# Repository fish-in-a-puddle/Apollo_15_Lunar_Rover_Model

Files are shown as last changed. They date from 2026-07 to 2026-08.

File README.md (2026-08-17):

# Apollo 15 Lunar Rover Model v0
A Bluetooth-controlled model of the Apollo 15 lunar rover using an Arduino Nano and an HC-05 Bluetooth module.

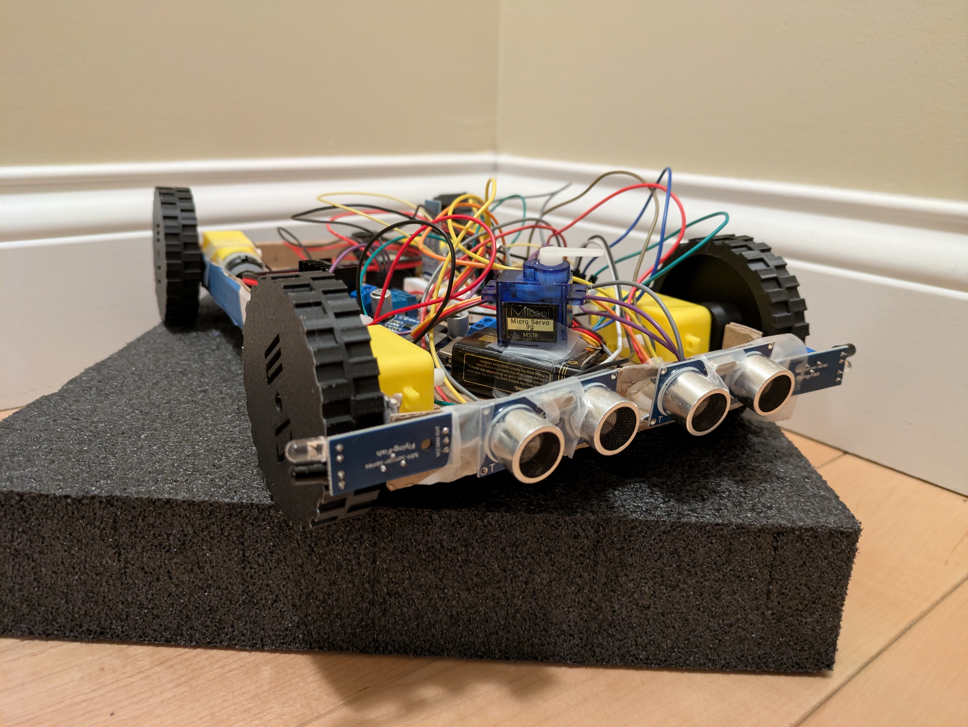
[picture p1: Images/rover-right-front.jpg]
Watch the demo! (https://youtu.be/fayXKmGm4Ek?si=QLX--hcnvoJ-vxXC)


Watch the demo on YouTube [here](https://youtu.be/fayXKmGm4Ek?si=QLX--hcnvoJ-vxXC).

#### Check out the project on Stardance! https://stardance.hackclub.com/projects/1942

## Description
The Apollo 15 Lunar Rover Model is a robot controlled by Bluetooth designed to look as similar as possible to the actual lunar roving vehicle used by Commander David Scott and Lunar Module Pilot James Irwin during the Apollo 15 mission. It can be driven using Bluetooth or set to navigate on its own using two ultrasonic sensors and two IR sensors. The ultrasonic sensors detect obstacles in the path of the rover as it moves forward and the IR sensors are used to check which direction is clear to turn backwards when the rover encounters an obstacle. It also has two LED headlights which can be turned on and off using bluetooth or set to turn themselves on and off depending on the light level detected by a photoresistor. The rover is powered by two 9v batteries: one to power the Arduino, HC-05 module and other components through a 9v-5v buck converter and one to provide power to the motors.

At the moment, the model doesn't look very similar to the actual roving vehicle. This is because the current version of the robot is a prototype built with cardboard to test the code and capabilities of the sensors. Version 0 is being shipped simply to show the process of creating the eventual version 1, which will feature a 3D printed chassis, an improved control app, and will resemble the actual rover much more. The rover is not very sturdy and is intended to be used as an educational tool or to be driven inside.

## Inspiration 
After watching NASA's contract award livestream and seeing some cool designs for future lunar rovers, I was inspired to make a robot modeled after the Apollo 15 Lunar Roving Vehicle. While the current version admittedly looks nothing like the actual rover, I am working on designing a 3d-printable chassis and accessories to pay tribute to the only lunar rover used during the Apollo missions.

The actual lunar roving vehicle

## Getting started
To get started with the current version of the Lunar Rover Model, you will first need to build the cardboard chassis. For instructions on building and wiring the rover, check out [this guide](Construction/building_the_chassis.md).

Once the chassis is built and the components are wired, it is time to flash the firmware to the Arduino. If you want your rover to simply drive itself around with no help from a driver, copy the code from lunar-rover-obstacle-detectv0.4.ino and paste it in the Arduino IDE. You can also download the file, place it in a folder named [lunar-rover-obstacle-detectv0.4](Firmware/lunar-rover-obstacle-detectv0.4.ino) and open it in the IDE. If you want the rover to be able to be driven or to be set to self-navigation, copy the code from [lunar-rover-completev0.2.ino](Firmware/lunar-rover-completev0.2.ino) and paste it in the Arduino IDE. Before flashing the code to the Arduino, you MUST disconnect the Bluetooth module from the Arduino. This is because if you don't, the Arduino will prioritize its serial communication with the Bluetooth module over the USB connection and you will get an error message.

To control the rover with Bluetooth, you will have to install a controller app on your device. I have used this one with great results: https://play.google.com/store/apps/details?id=com.tools.ArduinoBluetooth on Android. You will also need to make the buttons in the app send the correct code to the Arduino. The serial codes are as follows:

Forward = w

Backwards = s

Left = a

Right = d

Left backwards = z

Right backwards = c

Stop = x

Auto drive on = r

Auto drive off = e

Lights on = f

Lights off = g

Lights auto = h

Your configuration will probably look something like this:

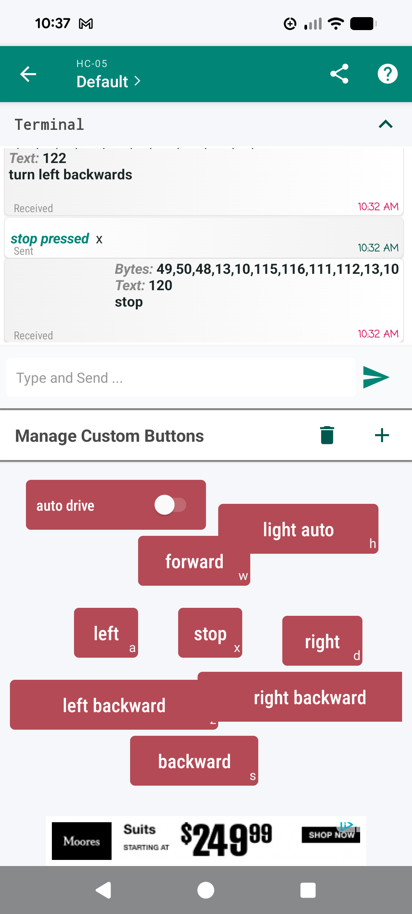
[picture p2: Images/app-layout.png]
Screenshot of app layout


After configuring the buttons in the app, you will be able to control the rover with your mobile device. If you use an iOs device, you may have to do some troubleshooting to find an app that works well. I was planning to make a custom app for the rover, but I don't know much about it and I wanted to focus on the rover itself. If anyone would like to make an app for this project, they are welcome to and I would appreciate if they let me know.

## Troubleshooting

If you are having issues with the motors, check that you have connected GND on the motor driver board to the ground rail on the breadboard as well as the ground of the battery.

If the rover is moving backwards randomly when when self-navigation is enabled, adjust the angle of the ultrasonic sensors. If they are tilted down they will pick up the floor as an obstacle.

If you are having trouble reconnecting the HC-05 to your phone, try making your phone "forget" the device and pair it again. You may be asked to enter a PIN to connect to the module. The code is usually 1234 or 0000.

If you encounter other problems, feel free to send a question to fish.in.a.puddle42@gmail.com. I'll see if I can help.

## Bill of Materials
|ITEM NAME |QTY |PRICE (CAD) |PRICE (USD) |LINK |NOTES |
|---|----|---|---|---|---|
|ELEGOO Arduino Nano | x1 | $33 | $23.68 | https://www.amazon.ca/ELEGOO-Pre-soldered-ATmega-Compatible-Arduino/dp/B0D5LYFRQP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 | The Arduino board used for the rover (Comes in a pack of three)|
|DC Hobby Motors | x4 | $6.59 | $4.70 | https://www.aliexpress.com/item/1005007259961932.html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| |
|L298N Motor Driver | x1 | $2.15 | $1.15 | https://www.aliexpress.com/item/1005012608321443.html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 | |
|HC-05 Bluetooth module | x1 | $6.90 | $5 | https://www.universal-solder.ca/product/hc-05-bluetooth-module-master-slave/?wmc-currency=CAD | The bluetooth module used for the rover |
|9v to 5v buck converter  | x1 | $4.84 | $3.49 | https://www.aliexpress.com/item/1005010708910916.html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 | |
|Ultrasonic sensor | x2 | $4 | $2.88 | https://www.universal-solder.ca/product/hc-sr04-ultrasonic-distance-sensor-module-2cm-400cm-range/ | Buy two |
|IR sensor | x2 | $1.12 | $0.81 | https://www.aliexpress.com/item/1005009143740555.html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 | Buy two |
|220 Ω resistor | x1 | $4.27 | $3.08 | https://www.aliexpress.com/item/1005011767578775.html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 | Pack of 20 |
|Photoresistor | x1 | $1.61 | $1.16 | https://www.amazon.ca/dp/B09ZTQL935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 | Pack of 20 |
|Yellow LED | x2 | $4 | $2.88 | https://www.universal-solder.ca/product/100-x-led-yellow-3mm-round-tinted-clear-standard-package-t-1/ | Pack of 100 |
|Micro Servo Motor | x1 | $8.49 | $6.12 | https://www.aliexpress.com/item/1005010200002677.html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 | |
|Rechargeable 9v batteries| x2 | $3.48 | $2.51 | https://www.aliexpress.com/item/1005007104927891.html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 | Pack of 10 |
|9v battery connectors | x2 | $3 | $2.16 | https://www.amazon.ca/Battery-Connector-Leather-Housing-Connection/dp/B0DHY6VX3L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 | Pack of 10 |
|On/Off rocker switch | x2 | $2 | $1.45 | https://www.amazon.ca/Boat-Rocker-Switch-5Pcs-Position/dp/B0DCNQHKDB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 | Pack of 5 |

## Credits

Original wheel models: https://www.thingiverse.com/thing:5636299

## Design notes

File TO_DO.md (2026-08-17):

# Hardware:
- [x] Put together cardboard frame
- [x] Run test sketch
- [x] Test 5v converter
- [x] Add servo, photoresistor and LEDs
- [ ] Model frame
- [x] Find better wheels

# Software:
- [x] Write test sketch
- [x] Write sketch for bluetooth 
- [x] Make initial app
- [x] Make first draft of final sketch integrating bluetooth and obstacle detection
- [x] Define the rest of the bluetooth recv valuesl

# Shipping prep:
- [x] Update README with instructions for building frame, wiring, flashing code
- [x] Make wiring simulation
- [x] Sort files into folders
- [x] Include instructions for app

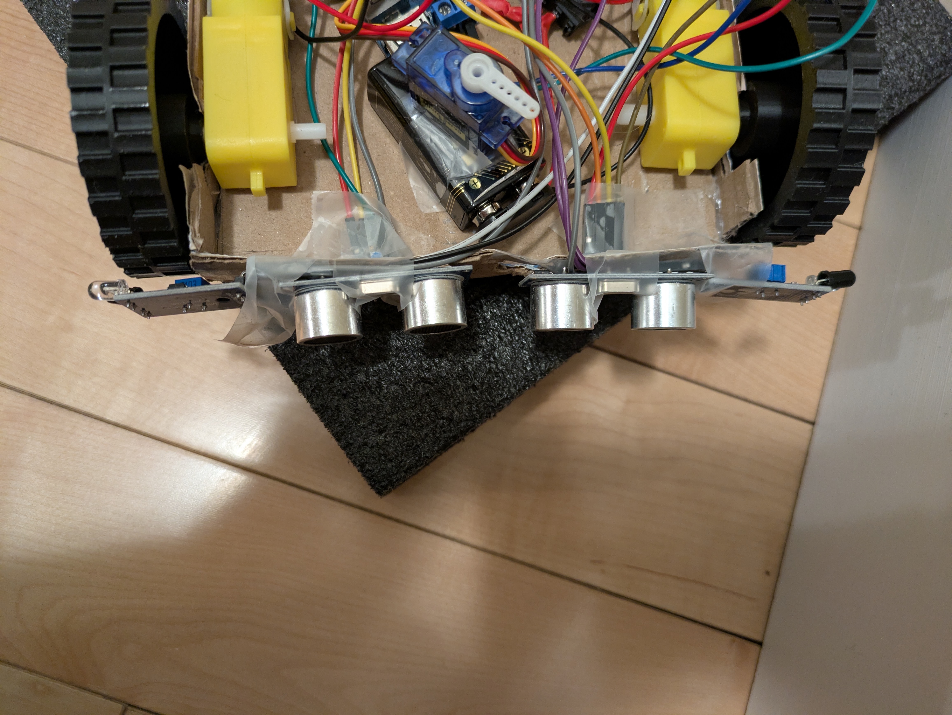
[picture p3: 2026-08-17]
Images/rover-front-top.jpg

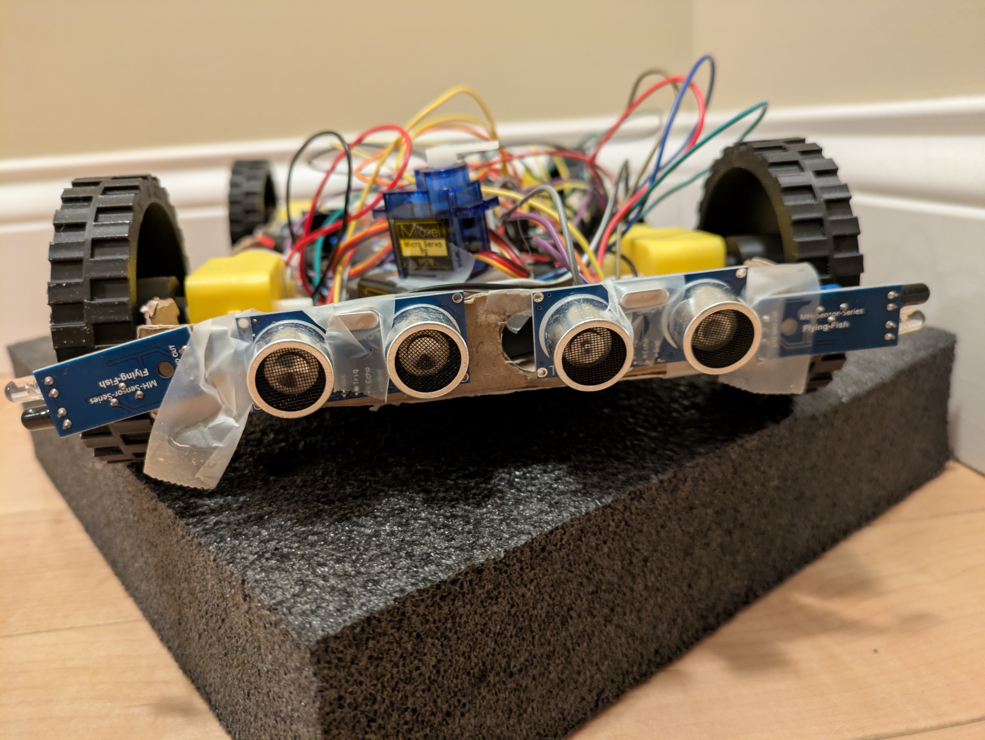
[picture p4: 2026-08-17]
Images/rover-front-closeup.jpg

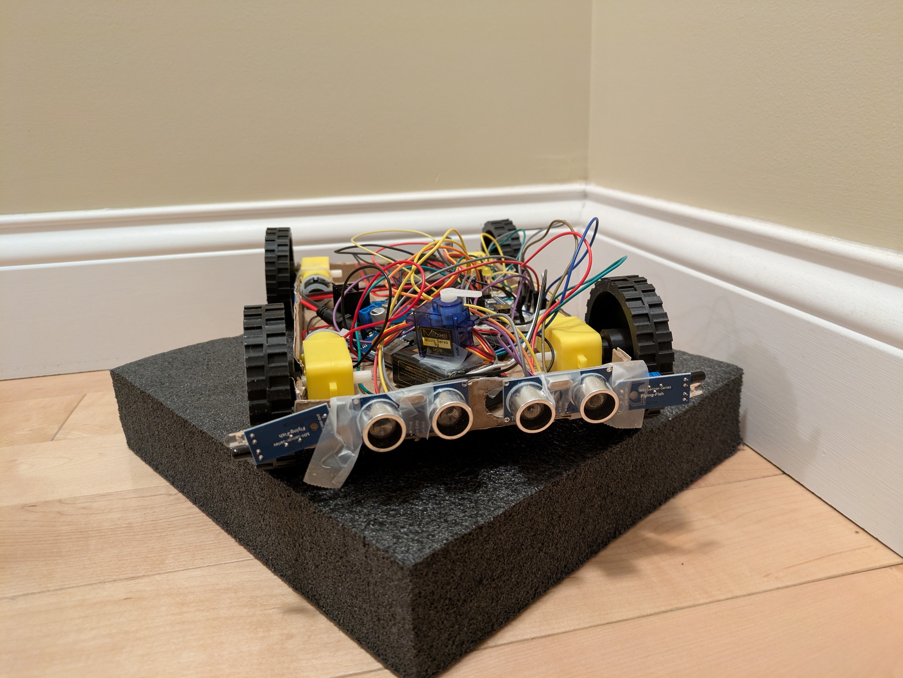
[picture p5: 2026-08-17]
Images/rover-front.jpg

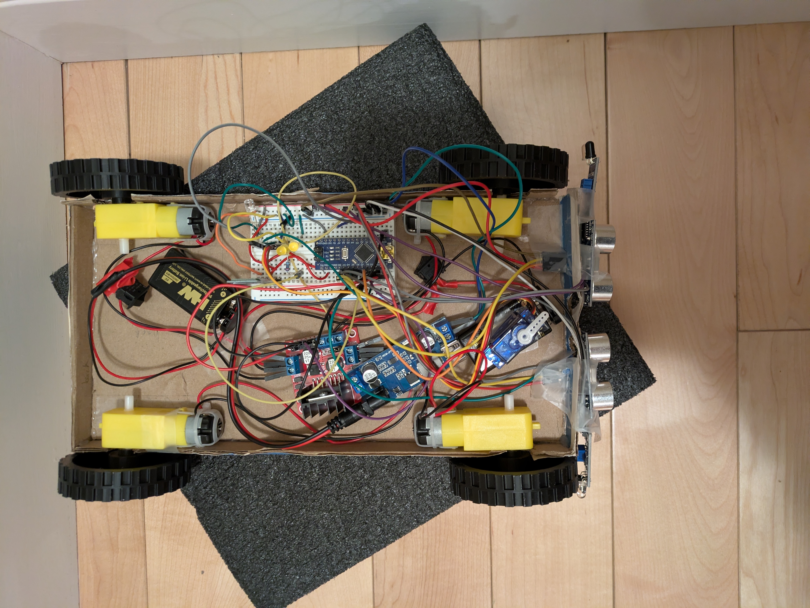
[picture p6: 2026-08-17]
Images/rover-top.jpg

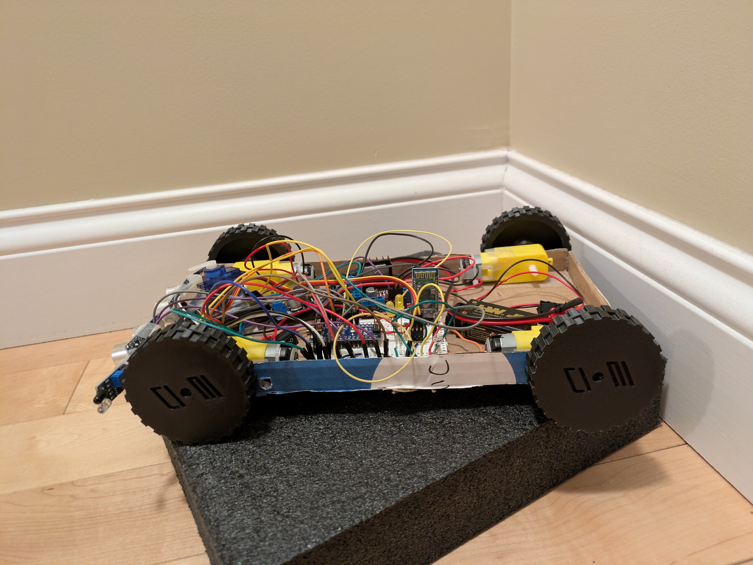
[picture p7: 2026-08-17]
Images/rover-left-side.jpg

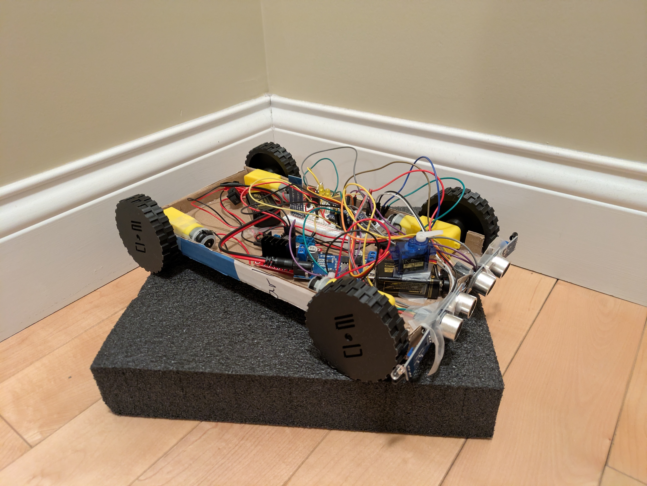
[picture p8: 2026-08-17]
Images/rover-right-side.jpg

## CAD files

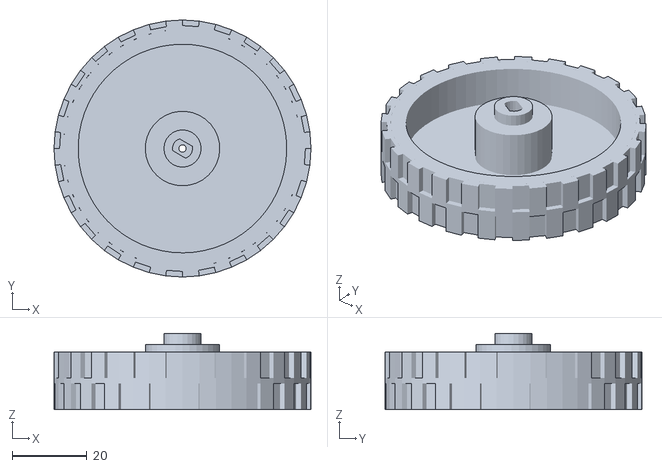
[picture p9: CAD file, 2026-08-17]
Construction/lunar-rover-wheels.stl
69.0 x 69.0 x 20.5

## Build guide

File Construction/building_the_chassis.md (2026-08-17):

# Building the chassis

To get started with the current version of the Lunar Rover Model, you will first need to build the cardboard chassis. The dimensions are as follows:
- Bottom plate: 140x280mm
- Side plates: 280x20mm
- Front & back plates: 140x20mm

Cut out one piece of cardboard for the bottom plate, two for the side plates and two for the top plate. Use a hot glue gun to glue the pieces together in a box shape. Arrange the yellow motors in the box and mark where the shaft should poke out. Use a pencil or hobby knife to create a generous hole to allow the shaft to turn freely. 

You will also need to 3D print four copies of the wheel provided in the "Construction" folder. When they are ready, you will have to line up the shaft of the motor to fit into the slot in the wheel. (You may have to sand the inside of the slot a bit if it's too tight.)

Position one IR sensor on each side of the front plate, making sure that the wheels don't block their range. Use a piece of masking tape or electrical tape to secure each one in place. Position the two ultrasonic sensors in between the IR sensors, with one or two centimeters in between them (it's okay if they overlap with the IR sensors) and push the four-pin headers through the cardboard. Use a small piece of tape to secure the top so they face forward.

rover-front-closeup

Place the Arduino Nano on a half-size breadboard and stick the breadboard in the box. Wire the Arduino, sensors, LEDs, photoresistor, servo motor and HC-05 Bluetooth module as shown in the diagram. Secure the motor driver board in the box as well and wire the motors. Be sure to connect a common ground between the Arduino and the motor driver board.

circuit diagram

Before adding either of the batteries, you will have to cut the red wire of both 9v battery connectors and solder an on/off switch to each one. This will make it so you don't have to pull apart your wiring to turn off the rover. When the switches are soldered and the connections wrapped in electrical tape to prevent short-circuits, connect one of the batteries to the motor driver board and the other to a 9v-5v buck converter. Connect the other side of the converter to the power and ground rails of the breadboard; and connect the 5v and GND pins of the Arduino to their respective rails.

If you are having trouble figuring out where the parts are supposed to go, check the photo gallery to see images of my configuration. It is very messy because this is a prototype so they may or may not be helpful to you. You may have to be creative in your configuration of the chassis, but as long as the wiring matches the diagram, the code will work.

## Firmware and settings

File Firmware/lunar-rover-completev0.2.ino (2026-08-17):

// The current Servo library is required for this program
#include <Servo.h>

// Establish pins and variables
const int motorrp = 11;
const int motorrn = 10;
const int motorlp = 13;
const int motorln = 12;
const int led = 7;
const int trigPin2 = 8;
const int echoPin2 = 3;
const int trigPin = 5;
const int echoPin = 6;
const int irr = 2;
const int irl = 4;
const int lightDetect = A0;
int lightLevel;
long duration;
int distance;
int distance2;
int obstacleRight;
int obstacleLeft;
int autoDrive = 0; 
int autoLights;
int btIn;
int ran;

Servo sweepServo;

void setup() {
    // Begin serial communication with the bluetooth module
    Serial.begin(9600);
    // Set pin modes and attach servo
    pinMode(motorrp, OUTPUT);
    pinMode(motorrn, OUTPUT);
    pinMode(motorlp, OUTPUT);
    pinMode(motorln, OUTPUT);
    pinMode(led, OUTPUT);
    pinMode(trigPin2, OUTPUT);
    pinMode(echoPin2, INPUT);
    pinMode(irr, INPUT);
    pinMode(irl, INPUT);
    pinMode(trigPin, OUTPUT);
    pinMode(echoPin, INPUT);
    sweepServo.attach(9);
    sweepServo.write(90);
}

// Establish functions for the rover's movement
void goForward() {
    digitalWrite(motorrp, HIGH);
    digitalWrite(motorrn, LOW);
    digitalWrite(motorlp, HIGH);
    digitalWrite(motorln, LOW);
}

void goBackward() {
    digitalWrite(motorrp, LOW);
    digitalWrite(motorrn, HIGH);
    digitalWrite(motorlp, LOW);
    digitalWrite(motorln, HIGH);
}

void turnRight() {
    digitalWrite(motorrp, LOW);
    digitalWrite(motorrn, LOW);
    digitalWrite(motorlp, HIGH);
    digitalWrite(motorln, LOW);
}

void turnRightBackwards() {
    digitalWrite(motorrp, LOW);
    digitalWrite(motorrn, LOW);
    digitalWrite(motorlp, LOW);
    digitalWrite(motorln, HIGH);
}

void turnLeft() {
    digitalWrite(motorrp, HIGH);
    digitalWrite(motorrn, LOW);
    digitalWrite(motorlp, LOW);
    digitalWrite(motorln, LOW);
}

void turnLeftBackwards() {
    digitalWrite(motorrp, LOW);
    digitalWrite(motorrn, HIGH);
    digitalWrite(motorlp, LOW);
    digitalWrite(motorln, LOW);
}

void stop() {
    digitalWrite(motorrp, LOW);
    digitalWrite(motorrn, LOW);
    digitalWrite(motorlp, LOW);
    digitalWrite(motorln, LOW);
}

void servoMotion() {
    sweepServo.write(random(20, 160));
    delay(random(50, 100));
}

void loop() {
    // Check if a bluetooth message has been received
    if (Serial.available() > 0) {
        btIn = Serial.read();
        Serial.println(btIn);
        // Decide what to do with the command
        switch (btIn) {
            case 119:
            Serial.println("go forward");
            goForward();
            break;
            case 100:
            Serial.println("turn right");
            turnRight();
            break;
            case 97:
            Serial.println("turn left");
            turnLeft();
            break;
            case 115:
            Serial.println("go backwards");
            goBackward();
            break;
            case 99:
            Serial.println("turn right backwards");
            turnRightBackwards();
            break;
            case 122:
            Serial.println("turn left backwards");
            turnLeftBackwards();
            break;
            case 120:
            Serial.println("stop");
            autoDrive = 0;
            stop();
            break;
            case 114:
            Serial.println("auto drive on");
            autoDrive = 1;
            break;
            case 101:
            Serial.println("auto drive off");
            autoDrive = 0;
            break;
            case 102:
            Serial.println("lights on");
            autoLights = 0;
            digitalWrite(led, HIGH);
            break;
            case 103:
            Serial.println("lights off");
            autoLights = 0;
            digitalWrite(led, LOW);
            break;
            case 104:
            Serial.println("auto lights active");
            autoLights = 1;
            break;
       }
    }
    // Check if auto drive is enabled
    if (autoDrive == 1) {
        // Run ulrasonic sensors to check if there is anything in front of the rover
        digitalWrite(trigPin, LOW);
        delayMicroseconds(2);
        digitalWrite(trigPin, HIGH);
        delayMicroseconds(10);
        digitalWrite(trigPin, LOW);
        duration = pulseIn(echoPin, HIGH);
        distance = duration * 0.034 / 2;
        digitalWrite(trigPin2, LOW);
        delayMicroseconds(2);
        digitalWrite(trigPin2, HIGH);
        delayMicroseconds(10);
        digitalWrite(trigPin2, LOW);
        duration = pulseIn(echoPin2, HIGH);
        distance2 = duration * 0.034 / 2;
        // If there is something in front of the rover, check if there is anything on each side and decide which way to turn to back out
        if (distance <= 30 || distance2 <= 30) {
            stop();
            obstacleRight = (digitalRead(irr));
            if (obstacleRight == HIGH) {
                obstacleLeft = (digitalRead(irl));
                if (obstacleLeft == HIGH) {
                    stop();
                }
                turnLeftBackwards();
            }
            else {
                turnRightBackwards();
            }
        }
        else {
            goForward();
        }
        delay(200);
    }
    // Check if auto lights are enabled
    if (autoLights == 1) {
        // Check the light levels and decide whether or not to turn on lights
        lightLevel = map(analogRead(lightDetect), 0, 1023, 1, 100);
        if (lightLevel << 51) {
            digitalWrite(led, HIGH);
        }
        else {
            digitalWrite(led, LOW);
        }
    }
    // Generate a random number to decide if the servo will move
    ran = random(1, 5000);
    if (ran == 3) {
        servoMotion();
    }
}

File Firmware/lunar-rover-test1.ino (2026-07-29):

// Necessary libraries: Servo
#include <Servo.h>

const int motorrp = 10;
const int motorrn = 11;
const int motorlp = 12;
const int motorln = 13;
const int trig = 5;
const int echo = 6;
const int ledr = 7;
const int ledl = 8;

Servo sweepServo;

void setup() {
    pinMode(motorrp, OUTPUT);
    pinMode(motorrn, OUTPUT);
    pinMode(motorlp, OUTPUT);
    pinMode(motorln, OUTPUT);
    pinMode(ledr, OUTPUT);
    pinMode(ledl, OUTPUT);
    sweepServo.attach(9);
    sweepServo.write(90);
    
}

void loop() {
    digitalWrite(motorrp, HIGH);
    digitalWrite(motorlp, HIGH);
    digitalWrite(motorrn, LOW);
    digitalWrite(motorln, LOW);
    delay(2000);
    digitalWrite(motorrp, LOW);
    delay(500);
    digitalWrite(motorrp, HIGH);
    delay(1000);
    digitalWrite(motorlp, LOW);
    delay(500);
    digitalWrite(motorlp, HIGH);
    delay(1000);
    digitalWrite(motorrp, LOW);
    digitalWrite(motorlp, LOW);
    delay(5000);
    digitalWrite(motorrn, HIGH);
    digitalWrite(motorln, HIGH);
    delay(2000);
    digitalWrite(motorrn, LOW);
    delay(500);
    digitalWrite(motorrn, HIGH);
    delay(1000);
    digitalWrite(motorln, LOW);
    delay(500);
    digitalWrite(motorln, HIGH);
    delay(1000);
    digitalWrite(motorrn, LOW);
    digitalWrite(motorln, LOW);
    delay(10000);

}

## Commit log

2026-08-01 Fix commands file type
    [lunar-rover-commands.ino]
2026-08-01 Add ultrasonic sensor functionality
2026-08-02 Add ir sensor functionality
2026-08-03 Change motion sensor to test for improvement
2026-08-03 Update obstacle detect for two two ultrasonic sensors
2026-08-05 Add commands for servo motor and photoresistor
2026-08-10 Start writing bill of materials
    [BOM.csv]
2026-08-14 Finish writing bill of materials
    [BOM.csv]
2026-08-14 Finish bill of materials
    [BOM.csv]
2026-08-14 Write tutorial for building chassis and wiring
2026-08-14 Place all file related to building the chassis/wiring in Construction folder
    [BOM.csv]
2026-08-14 Update BOM
    [BOM.csv]
2026-08-15 Upload wheel model
    [lunar-rover-wheels.stl]
2026-08-15 Move wheel models to Construction folder
    [lunar-rover-wheels.stl]
2026-08-17 Update bom to account for ali express pricing
    [BOM.csv]
2026-08-17 Add circuit diagram
2026-08-17 Update TO_DO.md to mark wiring simulation as complete
2026-08-17 Add Bill of Materials to README
